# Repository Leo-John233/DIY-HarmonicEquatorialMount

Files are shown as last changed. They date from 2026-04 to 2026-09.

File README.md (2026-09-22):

<div align="center">
  
  
</div>

## 📄 License / 开源协议

本项目采用组合开源协议，对软件和硬件部分分别进行授权：

* **Software / 软件部分** (如固件代码): 采用 [GNU General Public License v3.0 (GPL-3.0)](LICENSE-GPL) 授权，详细信息请参阅 `LICENSE-GPL` 文件
* **Hardware / 硬件部分** (如 PCB 设计、原理图、机械 3D 模型): 采用 [CERN Open Hardware Licence Version 2 - Strongly Reciprocal (CERN-OHL-S v2)](LICENSE-CERN) 授权，详细信息请参阅 `LICENSE-CERN` 文件

若参考了该项目希望能够指明参考来源，注明原作者，保持开源精神，欢迎大家在此基础上进行改进和创新，但请勿将本项目的设计用于商业用途，除非您获得了明确许可

## 🛑致各位试图拿本开源项目“创业”的商业奇才们
本着开源精神，我非常欢迎大家复刻、交流和自己动手做着玩，但如果您是抱着“低价造个赤道仪拿去卖”的伟大商业宏图，并且打算把原作者当免费技术顾问的，请仔细阅读以下几点：

**🚫本项目不提供“保姆级开厂培训”**
开源提供的是设计本身，不是您商业化流水线上的免费技术支持，如果您连最基本的“水平轴承在哪”、“圆弧槽是干啥用的”都看不明白，连 STP 文件导入 SolidWorks 都不知道怎么处理，建议先去补习一下基础的机械常识，我不负责为您解答“怎么装”、“怎么动”、“怎么改”，更不负责给您的工厂流水线工人做技术培训，请不要把原作者当成您的“免费技术顾问”，如果您不懂机械设计，请先学会自己看图纸，学会自己分析问题，学会自己解决问题

**✂️魔改出了 Bug，请自己背锅**
把模型等比缩放、乱改减速机孔位，改完之后跑来跟我抱怨“俯仰调节机构装不上”、“没法适配”、“太难理解”？拜托，自己魔改导致的问题，请不要跑来怪原作者，我都开源了，您还指望我给您的“定制缩水版”做免费 Debug 吗？

**💰嫌贵别用，用了别嫌**
一边刷着小红书觉得这套开源设计“好高级”，一边又跑来跟我吐槽用这套方案“成本涨了200块”、“太麻烦了”，觉得贵、觉得麻烦，您可以不用，既然决定要抄这套作业去赚钱，就别在原作者面前哭穷了，毕竟我也不想看到您辛辛苦苦开了个工厂，结果因为技术问题被客户投诉了还跑来找我背锅

**⚖️友情警告**
想拿这套类似结构随便改个外观就去大规模量产售卖？自己做着玩大家其乐融融，但如果要量产商用，请自己评估好侵权风险，别怪我没提醒过您，出了事请自己承担，别拉上我，开源不等于“免费商用”，如果您想拿去商用，请自己搞定技术壁垒，做好侵权风险评估，做好售后服务准备，做好质量控制准备，做好客户投诉处理准备，做好工厂管理准备，做好资金链管理准备，做好一切商业化运营的准备，不要到时候出了问题还跑来怪原作者

大家都很忙，祝您的“平价赤道仪”大卖，Peace & Love

👉 **[奇文共赏：点击此处阅读“白嫖式创业奇才”的逆天聊天实录](https://github.com/Leo-John233/DIY-Harmonic-Equatorial-Mount/blob/main/images/Chat%20history/readme.md)**

---
## DIY谐波赤道仪（已完成实拍与导星测试）

由于我厌倦了 EQ3D 赤道仪的沉重，我计划用更轻便的谐波赤道仪来替换它。然而市面上的谐波赤道仪价格较高，尤其是与 DIY 可实现的规格相比，因此这个项目就此诞生。该谐波赤道仪旨在不牺牲性能的前提下，兼顾高精度、便携性和经济性

该项目旨在解决业余天文设备中的关键问题：
- 成品支架价格高昂
- 缺乏开放性和灵活性
- 复杂性或与个人设置的不兼容

此款DIY谐波赤道仪优势是：
- 🧰**经济实惠**——总造价2900元左右，CNC加工零件价格低于1800元
- 🪶**相对便携**——不含底座重量7.5公斤
- 🏗️**易于搭建**——专为拥有基本工具的创客设计
- 💪**高性能**——已完成PHD2导星拍摄测试
- ⚠️**关于当前项目状态的说明**⚠️
该项目已完成通电、基础 GoTo、导星和约13kg实际成像负载下的实拍验证，稳定导星时段的 PHD2 总 RMS 通常约为 0.4″ 至 0.6″，不同装配、负载和环境下的结果可能有所差异

## ✨主要特点
| **特征** | **描述** |
| :----- | :----- |
| 安装类型 | GEM德式赤道仪 |
| 传动类型 | 谐波减速器+皮带传动+42步进电机 |
| 有效载重 | 设计最大载重 30 kg（建议配重），无配重设计载重 20-25 kg，当前已完成约 13 kg 实拍验证 |
| 减速器类型 | leaderdrive LHS-25-100-C-III |
| 控制系统 | OnStep/OnStepx |
| 连接类型 | USB-B；WIFI；蓝牙；集成DS3231SN时钟芯片 |
| 硬件功能 | RA轴制动器；RA/DEC轴光电传感器限位；DEC/RA轴光电传感器原点；<br>同时兼容step/dir，spi两种驱动模式(即兼容tmc2209，tmc5160)；12/24v输入 |
| 预计成本 | 2900 RMB |
| 预计重量 | 9.5 kg（包含鸠尾槽和纬度座） |
| 已测导星表现 | 稳定时段 PHD2 总 RMS 通常约为 0.4″ 至 0.6″ |

---

## 最终成效

自制谐波赤道仪的核心部件为 Leaderdrive 拆机二手工业谐波减速器，也适用于同规格的 25-100 谐波减速器






---

## 实拍与导星测试

本次拍摄目标为 **Herschel 36**

Herschel 36

| **实拍项目** | **配置** |
| :----- | :----- |
| 主摄影器材 | 铁皮桶全改小黑，搭配 MPCC 彗差校正镜 |
| 主相机 | Nikon D7000 |
| 导星相机 | ZWO ASI662MC |
| 实际成像负载 | 约 13 kg |
| 测试环境 | 微风 |

## 当前验证状态

- [√] 主控板通电和基础通信
- [√] OnStep ASCOM 连接
- [√] 基础 GoTo 和恒星时跟踪
- [√] PHD2 校准和闭环导星
- [√] Dither 和 Settling
- [√] 约 52 分 45 秒连续导星记录
- [√] 约 13 kg 实际成像负载下的 Herschel 36 实拍
- [√] 不同载重和重心位置下的多夜重复测试
- [√] 无配重与带配重状态下的系统对比
- [ ] 关闭导星修正和 Dither 后的长时间本征周期误差测试
- [ ] 不同焦距、曝光时间和环境条件下的长期实拍验证

## PHD2 导星测试

### 测试配置

| 项目 | 配置 |
| :--- | :--- |
| 测试软件 | PHD2 Guiding 2.6.13 |
| 赤道仪连接 | OnStep ASCOM |
| 导星相机 | ZWO ASI662MC |
| 导星焦距 | 200 mm |
| 导星相机像元尺寸 | 2.9 μm |
| 导星图像比例 | 约 2.99″/px |
| 导星曝光 | 0.2 s |
| 实际成像负载 | 约 13 kg |
| 测试环境 | 微风 |
| 完整记录时长 | 52 分 45 秒 |

### 结果汇总

| 测试片段 | RA RMS | Dec RMS | 总 RMS | 说明 |
| :--- | ---: | ---: | ---: | :--- |
| 稳定导星片段 | 0.43″ | 0.50″ | 0.66″ | PHD2 实时统计截图 |
| 52 分 45 秒完整记录 | 0.45″ | 0.82″ | 0.94″ | 包含 Dither、Settling 和少量异常峰值 |

实际使用过程中，稳定导星阶段的总 RMS 通常约为 0.4″ 至 0.6″。稳定片段截图显示总 RMS 为 0.66″，完整记录由于包含 Dither、Settling 和少量异常峰值，总 RMS 为 0.94″

### 结果分析

- **稳定阶段两轴误差较为均衡**：RA RMS 为 0.43″，Dec RMS 为 0.50″，两轴差值较小，未表现出明显的单轴持续振荡。总 RMS 为 0.66″，按 2.99″/px 的导星图像比例换算约为 0.22 px，其中 RA 约为 0.14 px，Dec 约为 0.17 px
- **完整记录的 RMS 主要由 Dec 瞬态波动拉高**：完整记录中的 RA RMS 为 0.45″，与稳定片段接近，说明 RA 长时间表现基本保持一致。Dec RMS 上升至 0.82″，表明完整记录中的 Dither、Settling、微风或少量异常峰值主要影响了 Dec 统计结果，不代表稳定跟踪阶段持续存在 0.82″ 的 Dec 误差
- **约 13 kg 实际负载下维持稳定导星**：在铁皮桶全改小黑、Nikon D7000、MPCC 和导星系统组成的约 13 kg 成像负载下，稳定阶段未观察到明显发散或持续性机械振荡，说明当前结构刚性、传动控制和导星响应能够满足实际成像需求
- **0.2 s 导星曝光体现了较快的修正响应**：较短曝光有助于快速修正误差，但也更容易受到视宁度和瞬时扰动影响。因此，0.4″ 至 0.6″ 应视为本次设备、参数和环境组合下的实测表现，不应直接作为所有场景下的固定性能指标
- **频域结果不能直接作为本征周期误差**：频域分析中选中的低频分量周期约为 2206.6 s，显示振幅约为 0.1″。由于数据来自导星记录，并包含低频漂移、Dither 和 Settling，该结果只能用于观察频率成分，不能直接认定为谐波减速器的本征周期误差

<details>
<summary>展开查看 PHD2 测试截图与频域分析</summary>

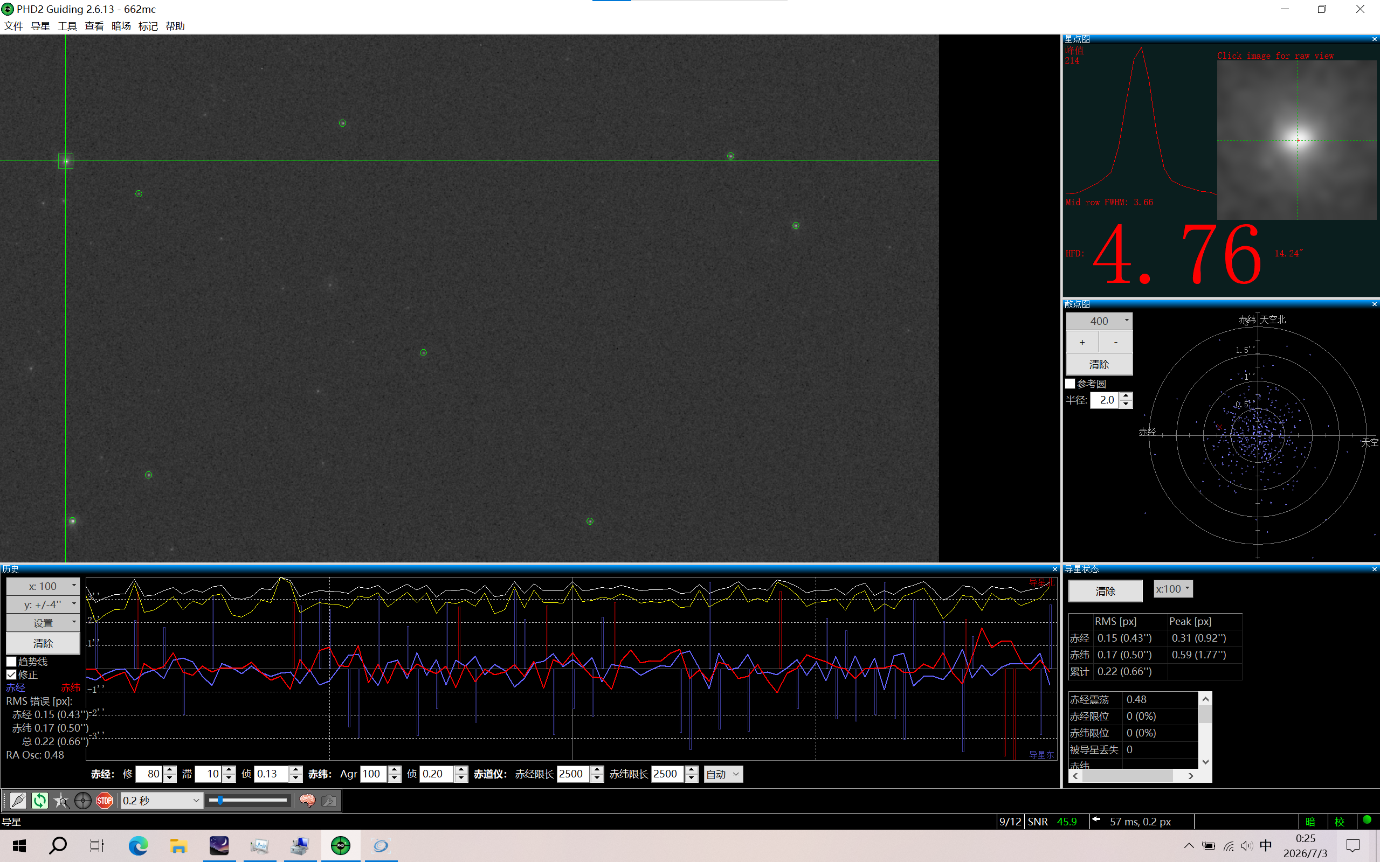
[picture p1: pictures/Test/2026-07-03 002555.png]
PHD2 stable guiding


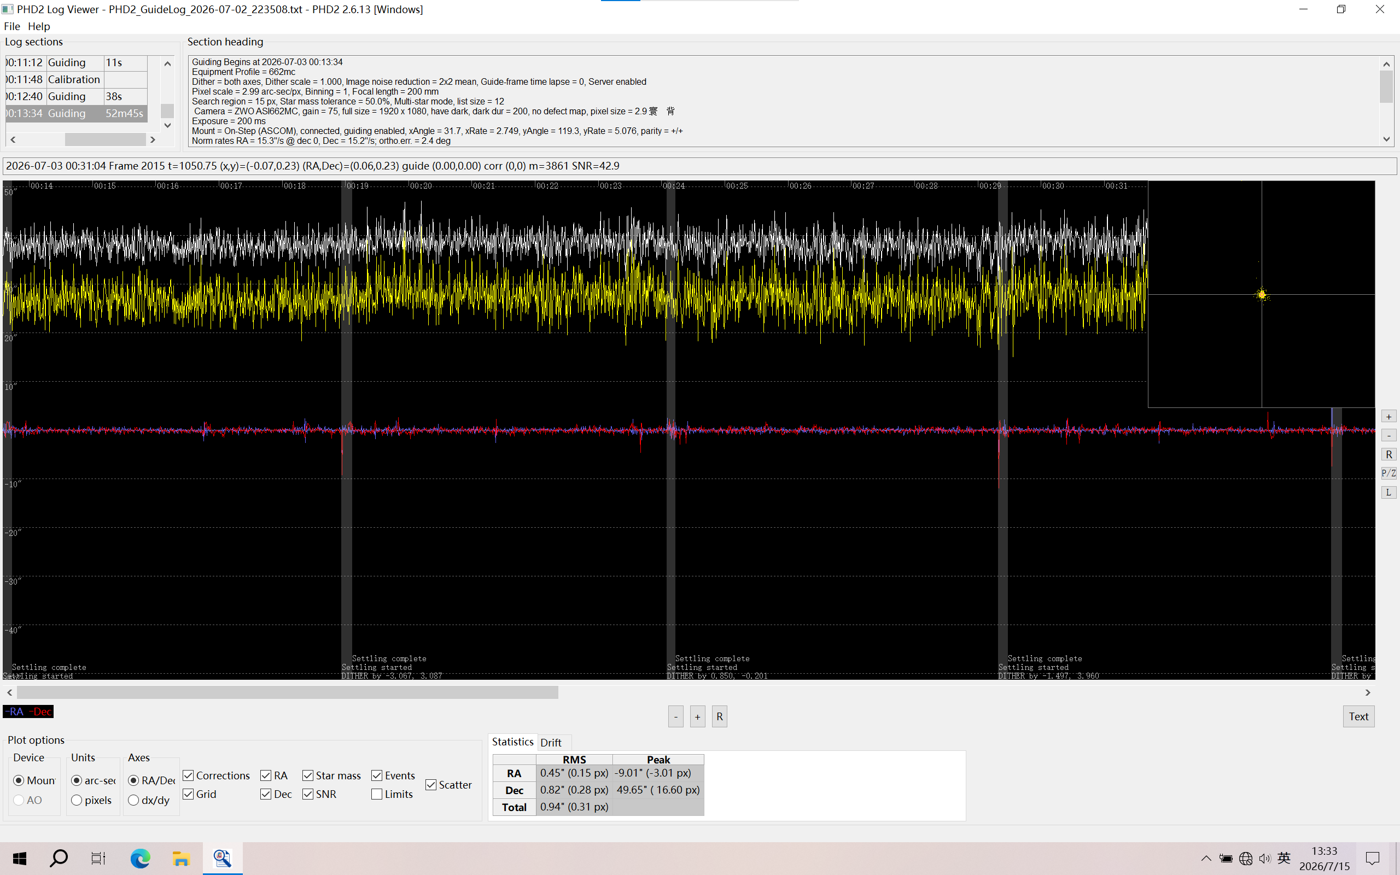
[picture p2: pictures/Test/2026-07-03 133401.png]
PHD2 complete log


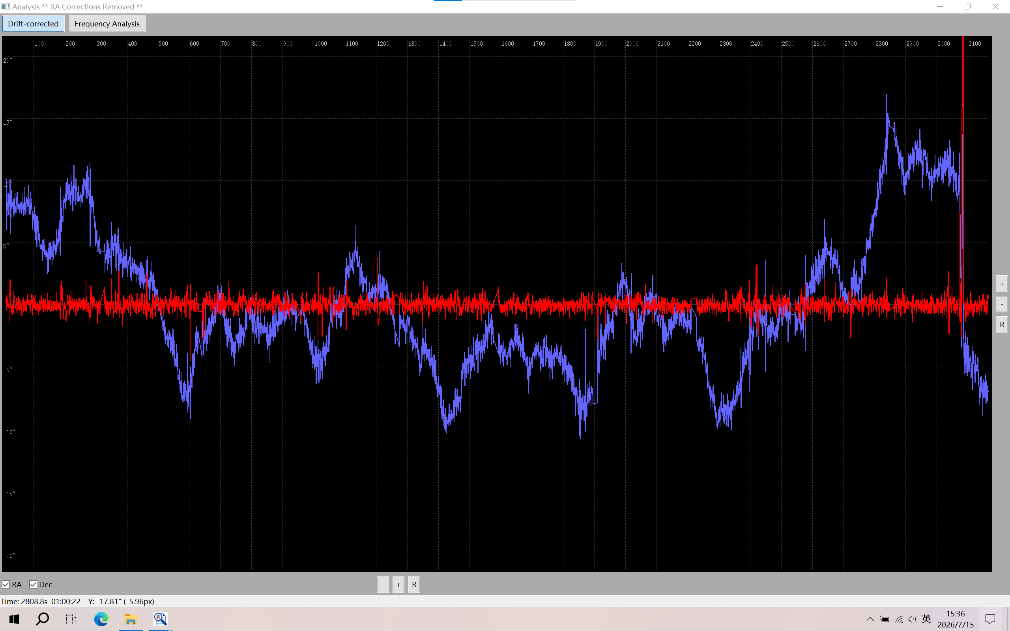
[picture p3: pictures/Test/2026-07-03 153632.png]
PHD2 drift-corrected analysis


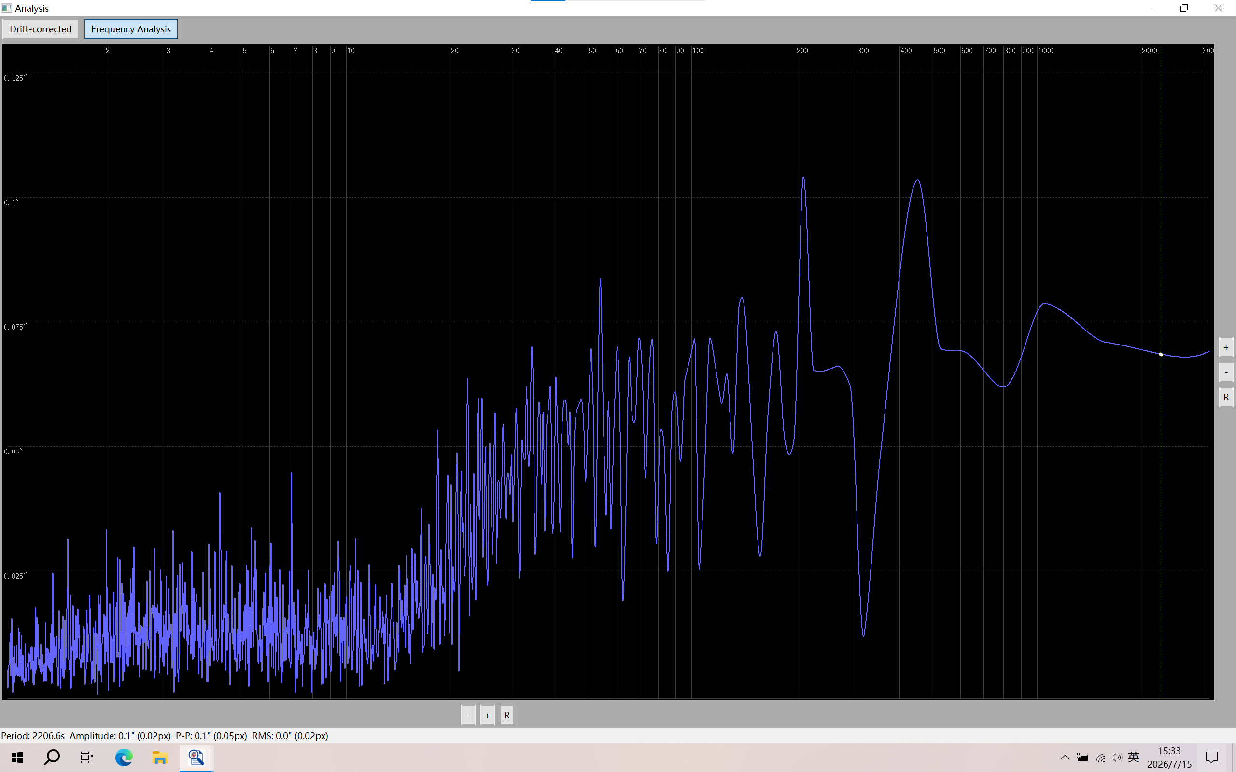
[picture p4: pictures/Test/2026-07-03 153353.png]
PHD2 frequency analysis


移除 RA 导星修正后的曲线仍包含低频漂移、Dither 和 Settling 的影响，不能直接将整段曲线的峰峰值视为谐波减速器的本征周期误差

频域分析中选中的低频分量周期约为 2206.6 s，软件显示振幅约为 0.1″。该结果仅用于观察频率成分，不能替代关闭导星修正和 Dither 后进行的长时间无导星周期误差测试

</details>

---

## 🔗 物料清单 (BOM)

请参阅 [BOM.md](https://github.com/Leo-John233/DIY-Harmonic-Equatorial-Mount/tree/main/BOM)

**预计总成本：约2500RMB（含纬度座）**

本项目的主体结构高度依赖定制，主要部件包含两台 25-100 规格的谐波减速器，提供了极高的传动比与扭矩，底座接口可根据个人习惯适配主流的三脚架

*注：价格为近似值，可能因电机供应商、CNC 加工批次和地点而异*

---

## 🔌电子部分概览

控制系统完全采用定制设计，并围绕紧凑结构构建，它包括：

* **基于 ESP32-WROOM-32E16N 的主控核心**，运行强大的 [OnStep/OnStepX](https://onstep.groups.io/g/main/wiki) 系统
* **搭配 ESP07S 无线连接**，提供高效的无线/有线通讯
* **TMC系列步进电机驱动器**，实现赤经与赤纬轴精确、静音的微步进控制与指向
* **高效电源管理方案**，板载 TPS5450 降压模块和 AMS1117 LDO 稳压芯片，确保高负载下系统电压的纯净与稳定
* 集成 **零位传感器和限位开关** 接口，在运行中保障设备的安全
* 支持通过 Wi-Fi、蓝牙或 USB 路由进行远程控制，无缝对接主流天文摄影软件生态 (N.I.N.A., INDI, ASCOM 等)
* 控制板在 PCB 走线设计上充分考虑了扩展性需求，通过主板驱动器插槽旁的排针跳线 (Jumpers)，您可以轻松地在先进的 **SPI 智能控制模式**和传统的 **STEP/DIR 独立模式**之间进行物理切换(切换后需刷写固件)

* **TMC5160 SPI 模式 (推荐配置) 🚀**
    * **硬件设置**：使用跳线帽闭合 SPI 专用的针脚组，将 ESP32 的 SPI 总线直接连接至 TMC5160 驱动器
    * **系统优势**：彻底告别手动调节电位器，允许 OnStep 固件直接读取和写入寄存器，您可以在 Web 界面或 `Config.h` 中实时配置运行/保持电流、精确设置细分数（Microstepping），并在 StealthChop（极致静音）和 SpreadCycle（高动态扭矩）模式之间智能切换，最大化释放谐波减速器的性能
    * **固件配合**：在 `Config.h` 中将赤经/赤纬驱动模型定义为 `TMC5160_SPI`

* **传统 STEP/DIR 模式 (向下兼容) 🔌**
    * **硬件设置**：断开 SPI 通讯跳线
    * **适用场景**：作为一种可靠的底层回退方案。如果您需要临时替换为普通的 A4988、DRV8825，或者仅使用 TMC 驱动器的 Standalone (独立运行) 模式，此设计提供了极大的硬件容错率和维修便利性
    * **固件配合**：需要在 `Config.h` 中精确填写您通过跳线帽设定的细分值，并**必须手动使用万用表和陶瓷螺丝刀**调节驱动器上的 VREF 电位器来设定电机电流

所有电路板原理图及 PCB Layout（严格把控了安全间距、过孔尺寸和大电流线宽）均使用开源工具设计，您可以在 [JLC PCB](https://member.jlc.com/?spm=PCB.Homepage) 订购 PCB或对其进行重新组合以满足您的需求

### PCB 制作与装配说明

PCB front

PCB reverse-side TMC5160 installation

PCB reverse-side TMC2209 installation

PCB 制作和装配建议按以下顺序进行：

1. **提交 PCB 文件**
   * 将仓库中对应版本的 Gerber 压缩包直接上传至 PCB 厂商
   * 下单前检查板框尺寸、安装孔、槽位和连接器开口，避免生产平台自动缩放或修改外形
   * 如果自行修改板厚、铜厚、表面处理或元件封装，需要重新确认外壳间隙、连接器高度和大电流走线能力

2. **核对元件和方向**
   * 焊接前根据原理图、BOM、PCB 丝印和封装方向逐项核对元件
   * 重点检查二极管、LED、电解电容、稳压芯片、ESP32、ESP-07S 和其他有方向要求的器件
   * CR1220 电池按 PCB 丝印方向安装，照片所示安装方式为正极朝外
   * ESP32 天线区域附近不要布置金属挡板、屏蔽片或紧贴外壳，以免影响无线连接

3. **建议焊接顺序**
   * 先焊接电阻、电容、二极管和小型 IC 等低矮贴片器件
   * 再焊接电源模块、排针、驱动器插座、按键和 LED 接口
   * 最后安装 XH2.54 插座、USB、网络接口、DC 插座、XT60 和其他较高连接器
   * TMC 驱动器、ESP 模块和纽扣电池应在完成短路检查和基础供电测试后再安装

4. **驱动器安装**
   * 驱动器安装在 PCB 背面，插入前必须核对 PCB 丝印与驱动器上的 `GND`、`VM`、`EN`、`STEP` 和 `DIR` 引脚
   * 不同厂商的 TMC2209 或 TMC5160 模块可能存在引脚、焊盘或散热结构差异，不能只根据模块外观判断方向
   * 使用 TMC5160 SPI 模式时闭合对应 SPI 跳线，并在固件中选择 `TMC5160_SPI`
   * 使用 TMC2209 或其他 STEP/DIR 驱动器时断开 SPI 跳线，并按照实际硬件设置填写细分参数和驱动电流
   * 驱动器插反或带电插拔可能立即损坏驱动器和主控板

5. **首次通电检查**
   * 通电前使用万用表检查主电源正负极之间是否存在明显短路
   * 首次测试建议使用带限流功能的实验电源，并从较低限流值开始
   * 首次通电时不要连接电机、传感器和驱动器，先确认电源部分没有异常发热，并检查主要电压轨是否正常
   * 确认主控、USB 通信和无线连接正常后，再逐个安装驱动器并连接 RA、Dec 电机
   * 初次电机测试应使用较低电流和较低速度，确认转向、原点和限位逻辑正确后再提高参数

6. **接口连接**
   * `LIMIT-RA`、`LIMIT-DEC`、`HOME-RA` 和 `HOME-DEC` 分别连接对应轴的限位和原点传感器
   * `RA-XH2.54`、`DEC-XH2.54` 和 `BRAKE` 接口应根据原理图确认引脚顺序后连接
   * 状态灯、连接灯和电源灯接口需要注意 LED 极性
   * 不建议同时连接多个主电源入口，除非已根据原理图确认其连接关系和使用方式

> 💡**警告：任何焊接、驱动器插拔、跳线调整、传感器接线或电机接线操作都必须在主电源和 USB 供电完全断开后进行，首次上电前应再次检查电源极性、焊锡短路、驱动器方向和连接器引脚顺序**

## 💻固件配置与刷写

谐波赤道仪的主控搭载了 **ESP32-WROOM-32E (16MB)**，这款大容量核心不仅能轻松运行复杂的 [OnStep / OnStepX](https://onstep.groups.io/g/main/wiki) 固件，还为内置星表、高精度对位模型 (Pointing Model) 以及功能丰富的 Smart Web UI 留出了充足的存储空间

请参阅 [Firmware_Setup.md](https://github.com/Leo-John233/DIY-Harmonic-Equatorial-Mount/blob/main/software/Firmware_Setup.md) 获取完整的 `Config.h` 参数表及详细引脚映射

---

## 🛠️机械部分组装指南

请参阅 [Assembly.md](https://github.com/Leo-John233/DIY-Harmonic-Equatorial-Mount/blob/main/hardware/Assembly.md)

每个组件都经过精心挑选或设计，以确保高机械精度和易于组装，从 CNC 加工的坚固铝制主体、25-100 谐波减速器，到步进电机和控制器的 3D 打印防护外壳，每一步都经过了严格的测试与指向模型校准，以实现亚角秒级的跟踪精度

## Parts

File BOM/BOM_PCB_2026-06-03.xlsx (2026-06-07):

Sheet: bom模板
 |  |  |  | Bill of Materials | BOM_Leo_V1_STEP/DIR/SPI(已验证)_PCB1_2026-06-03
 |  |  |  | Project Title： | OnStep
 |  |  |  | Variant:
 |  |  |  | Report Time： | 2026年6月3日 21:4:49
No. | Quantity | Comment | Designator | Footprint | Value | Manufacturer Part | Manufacturer | Supplier Part | Supplier | LCSC Price | Total
1 | 1 | CR1220-2 | B1 | BAT-SMD_CR1220-2 |  | CR1220-2 | QIJEY | C70381 | LCSC |  | #VALUE!
2 | 2 | TS-1101-C-W | BOOT, RESET | SW-SMD_L6.0-W3.3-LS8.0 |  | TS-1101-C-W | XKB Connectivity(中国星坤) | C318938 | LCSC |  | #VALUE!
3 | 1 | WAFER-XH254Z-2A | BRAKE | CONN-TH_2P-P2.50_XH-2A_3045048 |  | WAFER-XH254Z-2A | HANBO(汉博) | C7432682 | LCSC |  | #VALUE!
4 | 3 | 100uF | C1, C6, C7 | C1210 | 100uF | EMK325ABJ107MM-T | TAIYO YUDEN(太诱) | C394395 | LCSC |  | #VALUE!
5 | 2 | 4.7uF | C2, C3 | C0603_1 | 4.7uF |  |  |  |  |  | #VALUE!
6 | 4 | 10nF | C4, C5, C8, C10 | C0603_1 | 10nF |  |  |  |  |  | #VALUE!
7 | 1 | 10uF | C9 | C0603_1 | 10uF |  |  |  |  |  | #VALUE!
8 | 4 | 10uF | C11, C13, C15, C17 | C0805 | 10uF | CL21A106KAYNNNE | SAMSUNG(三星) | C15850 | LCSC |  | #VALUE!
9 | 4 | 100nF | C12, C14, C16, C18 | C0603 | 100nF | CL10B104KB8NNNC | SAMSUNG(三星) | C1591 | LCSC |  | #VALUE!
10 | 5 | 100nF | C19, C24, C25, C26, C27 | C0603 | 100nF |  |  |  |  |  | #VALUE!
11 | 1 | 10uF | C20 | CASE-A_3216 |  | T491A106K010AT | KEMET(基美) | C1508940 | LCSC |  | #VALUE!
12 | 1 | 100nF | C21 | C0603 | 100nF | CGA0603X7R104K500JT | HRE(芯声) | C6119867 | LCSC |  | #VALUE!
13 | 1 | 10uF | C22 | C0603 | 10uF | CGA0603X5R106K100JT | HRE(芯声) | C6119842 | LCSC |  | #VALUE!
14 | 1 | 1uF | C23 | C0603 | 1uF |  |  |  |  |  | #VALUE!
15 | 2 | 100uF | C28, C29 | CAP-SMD_BD6.3-L6.6-W6.6-LS7.3-FD-H7.7 | 100uF | JVJ50V100M6x8 | JIERR(捷而瑞) | C46550415 | LCSC |  | #VALUE!
16 | 1 | XT30U-M | CN1 | CONN-TH_XT30U-M |  | XT30U-M | AMASS(艾迈斯) | C99101 | LCSC |  | #VALUE!
17 | 1 | RA-XH254 | CN2 | CONN-TH_XH-4A |  | WAFER-XH254Z-4A | HANBO(汉博) | C7432684 | LCSC |  | #VALUE!
18 | 1 | DEC-XH254 | CN3 | CONN-TH_XH-4A |  | WAFER-XH254Z-4A | HANBO(汉博) | C7432684 | LCSC |  | #VALUE!
19 | 1 | SK1045C | D1 | SMC_L6.9-W5.9-LS7.9-RD |  | SK1045C | R+O(宏嘉诚) | C18199212 | LCSC |  | #VALUE!
20 | 1 | SMAJ28A | D2 | SMA_L4.3-W2.6-LS5.2-RD |  | SMAJ28A | 晶导微电子 | C353458 | LCSC |  | #VALUE!
21 | 3 | 1N5819W | D3, D6, D7 | SOD-123_L2.7-W1.6-LS3.7-RD |  | 1N5819W | GOODWORK(固得沃克) | C41431973 | LCSC |  | #VALUE!
22 | 1 | SMF5.0A | D4 | SOD-123FL_L2.7-W1.8-LS3.8-RD |  | SMF5.0A | R+O(宏嘉诚) | C19077497 | LCSC |  | #VALUE!
23 | 1 | 1N4007 | D5 | SMA_L4.3-W2.5-LS5.0-RD |  | 1N4007 | TWGMC(迪嘉) | C727081 | LCSC |  | #VALUE!
24 | 1 | PRTR5V0U2X | D9 | SOT-143-4_L2.9-W1.3-P1.92-LS2.4-BL |  | PRTR5V0U2X | TECH PUBLIC(台舟) | C2827688 | LCSC |  | #VALUE!
25 | 1 | DC005 | DC1 | DC-IN-TH_DC005 |  | DC005 | SHOU HAN(首韩) | C431533 | LCSC |  | #VALUE!
26 | 1 | K0805L100AR | F1 | F0805 |  | K0805L100AR | KUU | C2892413 | LCSC |  | #VALUE!
27 | 3 | HC-ZH1.5-2A | HOME-BUTTON, POWER-LED, STATUS-LED | CONN-TH_2P-P1.50_HCTL_HC-ZH1.5-2A |  | HC-ZH1.5-2A | HCTL(华灿天禄) | C2845550 | LCSC |  | #VALUE!
28 | 1 | 15uH | L1 | IND-SMD_L7.0-W6.6 | 15uH | FXL0650-150-M | cjiang(长江微电) | C475522 | LCSC |  | #VALUE!
29 | 1 | GL0603UR01 | LINK-LED | LED0603-FD |  | GL0603UR01 | Guiguang light(桂光光电) | C51933292 | LCSC |  | #VALUE!
30 | 2 | SS8050 | Q1, Q2 | SOT-23-3_L2.9-W1.3-P1.90-LS2.4-BR |  | SS8050 | JSMSEMI(杰盛微) | C916392 | LCSC |  | #VALUE!
31 | 1 | 10K | R1 | R0603_1 | 10K |  |  |  |  |  | #VALUE!
32 | 1 | 3.16K | R2 | R0603_1 | 3.16K |  |  |  |  |  | #VALUE!
33 | 2 | 510Ω | R3, R4 | R0603 | 510Ω | 0603WAF5100T5E | UNI-ROYAL(厚声) | C23193 | LCSC |  | #VALUE!
34 | 2 | 12kΩ | R5, R6 | R0603 | 12kΩ | 0603WAF1202T5E | UNI-ROYAL(厚声) | C22790 | LCSC |  | #VALUE!
35 | 1 | 2K | R7 | R0603 | 2K |  |  |  |  |  | #VALUE!
36 | 5 | 4.7K | R8, R12, R13, R14, R15 | R0603 | 4.7K |  |  |  |  |  | #VALUE!
37 | 2 | 10K | R9, R11 | R0603 | 10K |  |  |  |  |  | #VALUE!
38 | 2 | 3.3K | R10, R16 | R0603 | 3.3K |  |  |  |  |  | #VALUE!
39 | 1 | 5301-6P6C | RJ1 | RJ45-TH_5301-6P6C |  | 5301-6P6C | EVERCOM(恒连) | C3097716 | LCSC |  | #VALUE!
40 | 2 | 4.7kΩ | RN1, RN2 | RES-ARRAY-SMD_0603-8P-L3.2-W1.6-BL | 4.7kΩ | 4D03WGJ0472T5E | UNI-ROYAL(厚声) | C1980 | LCSC |  | #VALUE!
41 | 2 | ZX-PZ1.27-1-2PZZ | RST, SPI | HDR-TH_2P-P1.27-V-M-2 |  | ZX-PZ1.27-1-2PZZ | Megastar(兆星) | C41370734 | LCSC |  | #VALUE!
42 | 4 | M3螺孔 | TP1, TP2, TP3, TP4 | M3螺孔外直径6MM |  |  |  |  |  |  | #VALUE!
43 | 1 | TPS5450DDAR | U1 | SOP-8_L4.9-W3.9-P1.27-LS6.0-BL-EP |  | TPS5450DDAR | TI(德州仪器) | C114425 | LCSC |  | #VALUE!
44 | 2 | AMS1117-3.3 | U2, U3 | SOT-223-4_L6.5-W3.5-P2.30-LS7.0-BR |  | AMS1117-3.3 | UMW(友台半导体) | C347222 | LCSC |  | #VALUE!
45 | 1 | CP2102-GMR | U4 | WQFN-28_L5.0-W5.0-P0.50-BL-EP3.2 |  | CP2102-GMR | SKYWORKS/SILICON LABS(芯科) | C6568 | LCSC |  | #VALUE!
46 | 1 | ESP32-WROOM-32E-N16 | U5 | WIFI-SMD_ESP32-WROOM-32E |  | ESP32-WROOM-32E-N16 | ESPRESSIF(乐鑫) | C701343 | LCSC |  | #VALUE!
47 | 1 | ESP-07S | U6 | WIRELM-SMD_ESP-07S | 2.4GHz | ESP-07S | Ai-Thinker(安信可) | C82895 | LCSC |  | #VALUE!
48 | 1 | DS3231SN# | U7 | SOIC-16_L10.3-W7.5-P1.27-LS10.3-BL |  | DS3231SN# | ADI(亚德诺)/MAXIM(美信) | C722469 | LCSC |  | #VALUE!
49 | 1 | HOME-RA | U8 | CONN-TH_XH-3A |  | HOME-RA | HANBO(汉博) | C7432683 | LCSC |  | #VALUE!
50 | 1 | LIMIT-RA | U9 | CONN-TH_XH-3A |  | LIMIT-RA | HANBO(汉博) | C7432683 | LCSC |  | #VALUE!
51 | 1 | HOME-DEC | U10 | CONN-TH_XH-3A |  | HOME-DEC | HANBO(汉博) | C7432683 | LCSC |  | #VALUE!
52 | 1 | LIMIT-DEC | U11 | CONN-TH_XH-3A |  | LIMIT-DEC | HANBO(汉博) | C7432683 | LCSC |  | #VALUE!
53 | 1 | TMC2209-RA | U12 | TMC2209 |  |  |  |  |  |  | #VALUE!
54 | 1 | TMC2209-DEC | U13 | TMC2209 |  |  |  |  |  |  | #VALUE!
55 | 1 | USB-B10-BRW | USB1 | USB-B-TH_USB-B10-BRW |  | USB-B10-BRW | XUNPU(讯普) | C720549 | LCSC |  | #VALUE!
56 | #VALUE!

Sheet: Field汇总
Project Title | OnStep
Borard Title | Leo_V1_STEP/DIR/SPI(已验证)
Schematic Title | Schematic1
PCB Title | PCB1
Variant Name
Total Quantity | 92
Report Time | 21:4:49
Report Date | 2026年6月3日
Report Date&Time | 2026年6月3日 21:4:49
File Name | BOM_Leo_V1_STEP/DIR/SPI(已验证)_PCB1_2026-06-03
Filter Option | Add into BOM:no;

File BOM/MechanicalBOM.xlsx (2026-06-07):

纬度座部分
名称 | 规格 | 数量
塞打螺栓 | M8*10*M6 | 2 | https://detail.tmall.com/item.htm?id=601075915248&skuId=5681343815429
塞打螺栓 | M8*8*M6 | 2 | https://detail.tmall.com/item.htm?id=601075915248&skuId=5790216147369
一字塞打螺栓 | M8*10*M6 | 2 | https://detail.tmall.com/item.htm?id=706829568952&skuId=5886571346823
12.9级杯头螺丝 | M5*18 | 8 | https://detail.tmall.com/item.htm?id=636950471592&skuId=4572720393404
304不锈钢家具大平头倒边内六角螺丝 | M6*12 | 1 | https://detail.tmall.com/item.htm?id=859903073791
304不锈钢内螺纹圆柱销 | Φ12*25*M6 | 1 | https://detail.tmall.com/item.htm?id=597217503705&skuId=5510229308653
小微型推力球平面轴承 | F8-14M 尺寸8*14*4 | 2 | https://detail.tmall.com/item.htm?id=586706057051&skuId=5729732388208
304不锈钢一字开槽轴位螺丝钉 | φ6*6(M5*6) | 2 | https://item.taobao.com/item.htm?id=632002464537&skuId=5559277728820
圆切边法兰铜合金无油衬套黄铜铜套 | 8-15(27*4/8*12*15)-圆光 | 2 | https://detail.tmall.com/item.htm?id=561388884402
12.9级杯头螺丝 | M5*14 | 2 | https://detail.tmall.com/item.htm?id=587639753812&skuId=4942038499904
薄头内六角螺丝钉DIN7984 | M3*4 | 4 | https://detail.tmall.com/item.htm?id=611120761311&skuId=4924269517558
铜垫片 | M8*12*0.5 | 4 | https://detail.tmall.com/item.htm?id=626549373648
铜垫片 | M5*9*0.5 | 2 | https://detail.tmall.com/item.htm?id=626549373648
不锈钢超薄垫片 | M8*12*0.1 | 4 | https://detail.tmall.com/item.htm?id=610746766031
不锈钢超薄垫片 | M8*12*0.2 | 4 | https://detail.tmall.com/item.htm?id=610746766031
12.9级薄头内六角螺丝DIN7984 | M4*16 | 8 | https://detail.tmall.com/item.htm?id=600935021724
12.9级薄头内六角螺丝DIN7984 | M4*12 | 4 | https://detail.tmall.com/item.htm?id=600935021724
12.9级高强度镀镍薄头内六角螺丝 | M6*12 | 4 | https://detail.tmall.com/item.htm?id=852888071845
带钩拉簧 | 0.8*5*20 | 4 | https://detail.tmall.com/item.htm?id=625341852315
304不锈钢圆柱销销钉 | M3*18 | 4 | https://detail.tmall.com/item.htm?id=587625731480
304不锈钢薄头内六角螺丝 | M6*14 | 2 | https://detail.tmall.com/item.htm?id=15880165683
304不锈钢薄头内六角螺丝钉DIN7984 | M3*10 | 4 | https://detail.tmall.com/item.htm?id=611120761311
RN方形四方防松锁紧螺母螺 | RN-M8*1.0 | 2 | https://item.taobao.com/item.htm?ali_trackid=282_ddc27389fe7606c30299c8967ceb7956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
304不锈钢牙条细牙丝杆 | M8*120 | 1 | https://detail.tmall.com/item.htm?id=862294829769&skuId=5680688716227
梅花手拧螺栓 | M6x45mm | 2 | https://item.taobao.com/item.htm?id=973695181639
赤道仪部分
名称 | 规格 | 数量
铝合金四方六面螺母 | 15*15*15-M5 | 8 | https://item.taobao.com/item.htm?id=734244001867
铝合金四方六面螺母 | 10*10*10-M4 | 2 | https://item.taobao.com/item.htm?id=734244001867&skuId=5096386476347
304不锈钢家具大平头倒边内六角螺丝 | M4*8 | 4 | https://item.taobao.com/item.htm?id=743652912113
304不锈钢家具大平头倒边内六角螺丝 | M6*8 | 16 | https://item.taobao.com/item.htm?id=743652912113
304不锈钢圆头内六角螺丝 | M3*10 | 16 | https://detail.tmall.com/item.htm?id=587776166655
304不锈钢螺母 | M3 | 10 | https://detail.tmall.com/item.htm?id=1013711773809
内六角螺丝12.9级高强度镀镍杯头螺栓 | M4*45半牙 | 4 | https://detail.tmall.com/item.htm?id=621643553473
内六角螺丝12.9级高强度镀镍杯头螺栓 | M4*40半牙 | 24 | https://detail.tmall.com/item.htm?id=621643553473
304/316不锈钢尼龙锁紧螺母 | M4 | 24 | https://detail.tmall.com/item.htm?id=556902193652
六角铜柱单头铜螺柱 | M3*25+4 | 6 | https://detail.tmall.com/item.htm?id=601878143598
六角铜柱单头铜螺柱 | M3*15+3 | 4 | https://detail.tmall.com/item.htm?id=601878143598
12.9级半牙内六角螺丝 | M3*45 | 4 | https://detail.tmall.com/item.htm?id=695021175011
内六角螺丝12.9级高强度镀镍杯头螺栓 | M4*20 | 25 | https://detail.tmall.com/item.htm?id=621643553473
12.9级薄头内六角螺丝DIN7984 | M4*16 | 6 | https://detail.tmall.com/item.htm?id=600935021724
步进电机电磁制动器弹簧挤压机械刹车12v | 圆轴5×4.5mm | 1 | https://item.taobao.com/item.htm?id=833619009457
雷赛电机42CM06 | 双轴电机42CM06-SZ/47高度 | 1 | https://item.taobao.com/item.htm?id=670665930208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
雷赛电机42CM06 | 单轴电机42CM06-SZ/47高度 | 1 | https://item.taobao.com/item.htm?id=670665930208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
槽型形光电开关 | NPN | 4 | https://detail.tmall.com/item.htm?id=742487483554
土八热熔螺母 | M3*6*4.6 | 10 | https://detail.tmall.com/item.htm?id=809364062256

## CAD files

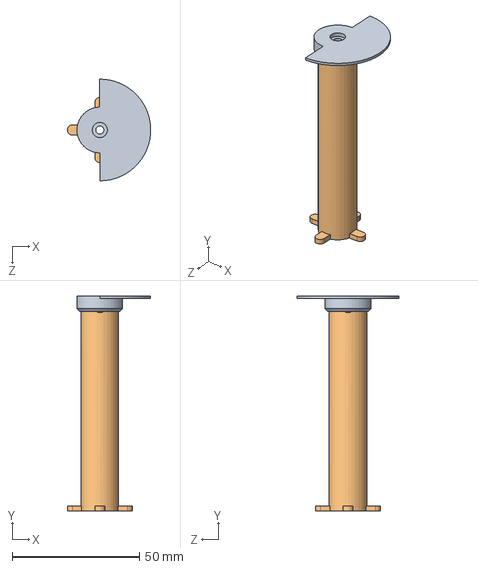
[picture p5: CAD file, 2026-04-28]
hardware/SW2024/赤道仪本体/组合体/RA轴+180度.SLDASM
32.8 x 84.5 x 40.0 mm
RA轴
180度限位盘

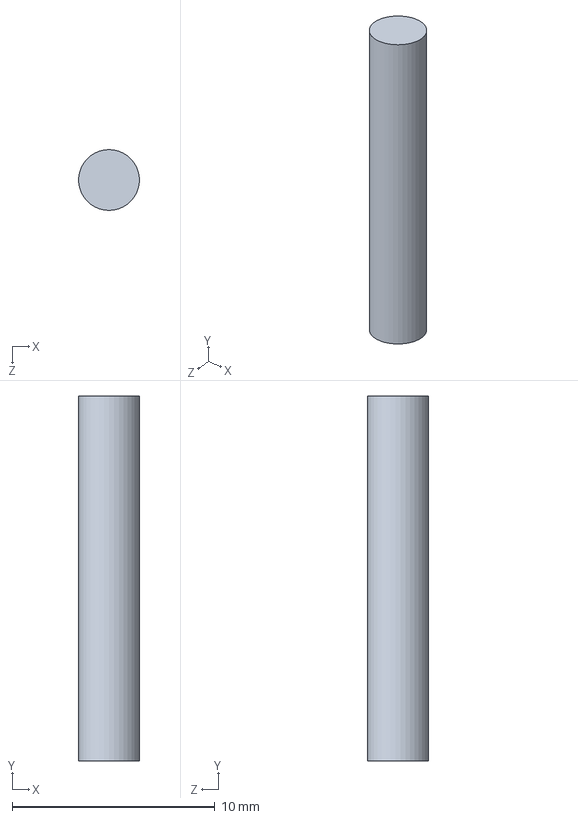
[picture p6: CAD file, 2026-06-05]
hardware/SW2024/纬度座/Spring Pin 3x10.SLDPRT
2.99 x 18.0 x 3.00 mm

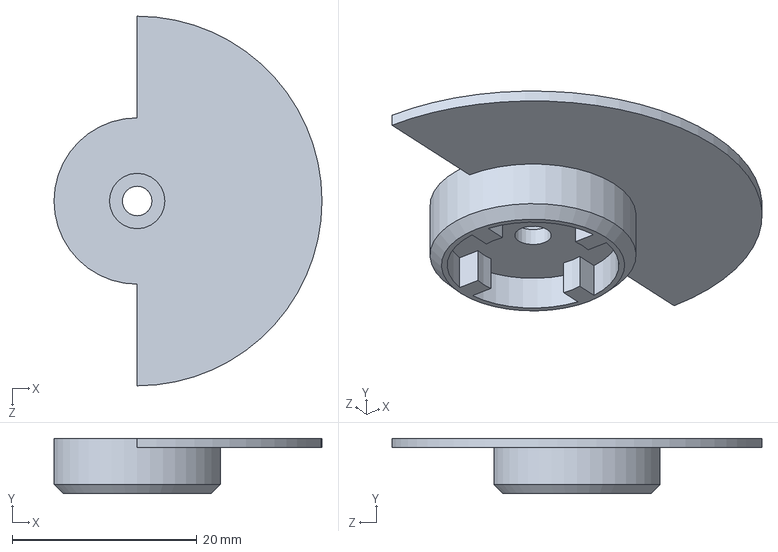
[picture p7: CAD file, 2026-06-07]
hardware/SW2024/赤道仪本体/180度限位盘.SLDPRT
29.0 x 6.00 x 40.0 mm

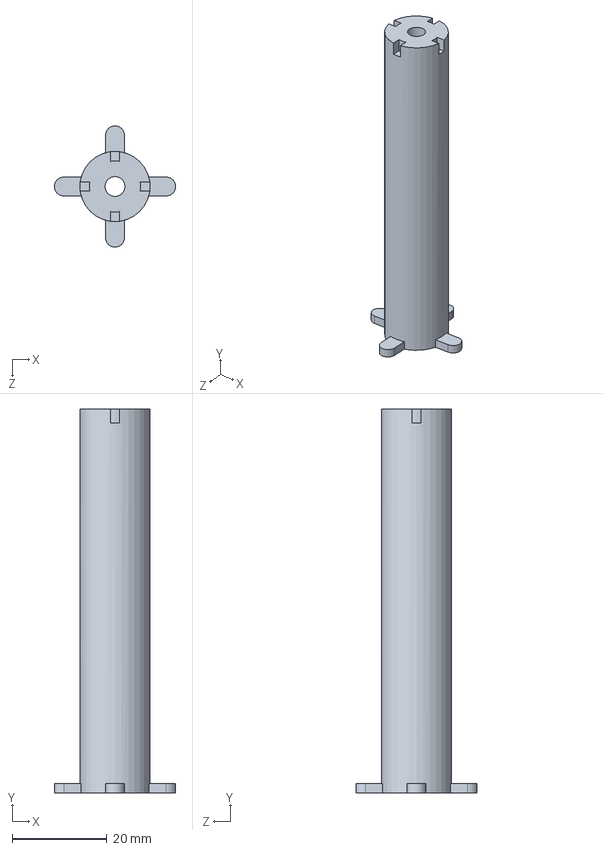
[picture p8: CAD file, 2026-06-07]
hardware/SW2024/赤道仪本体/RA轴.SLDPRT
25.6 x 81.0 x 25.6 mm

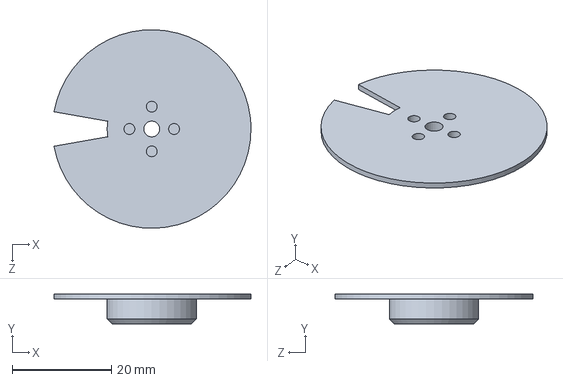
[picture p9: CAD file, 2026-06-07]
hardware/SW2024/赤道仪本体/340度限位盘 - DEC.SLDPRT
39.7 x 6.00 x 40.0 mm

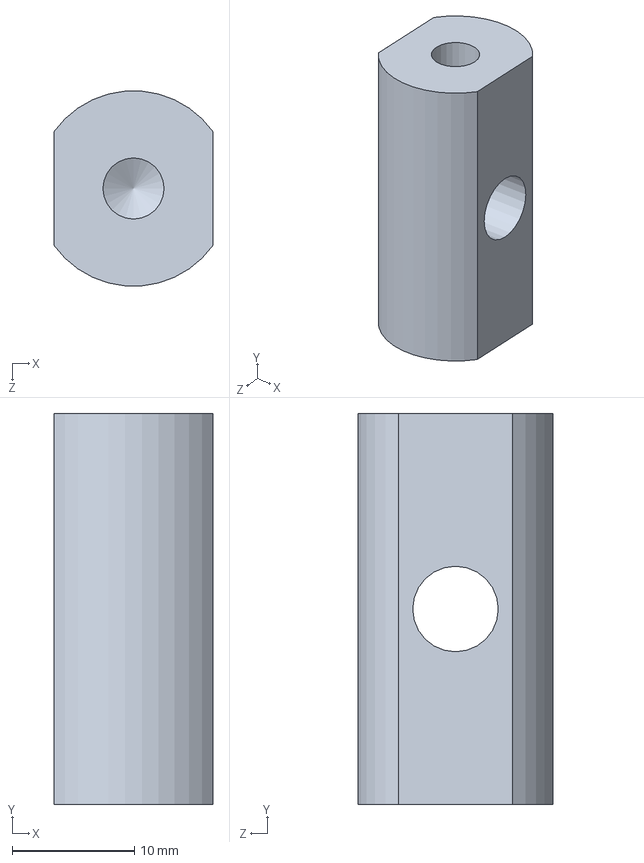
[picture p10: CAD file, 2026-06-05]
hardware/SW2024/纬度座/铜棒A.SLDPRT
13.0 x 32.0 x 15.9 mm

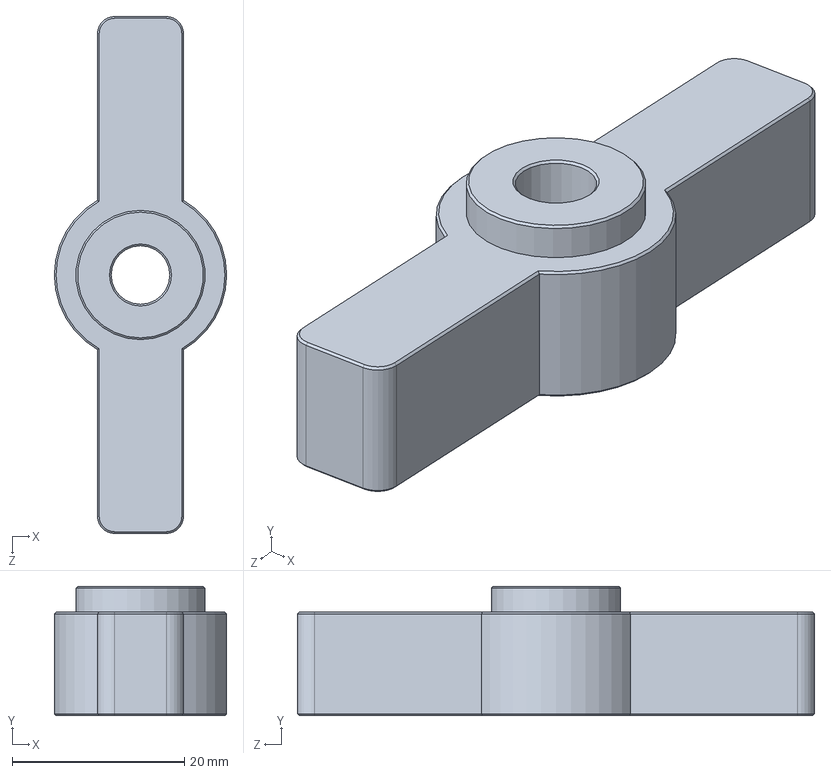
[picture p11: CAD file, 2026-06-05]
hardware/SW2024/纬度座/Thumbscrew Handle.SLDPRT
20.0 x 15.0 x 60.0 mm

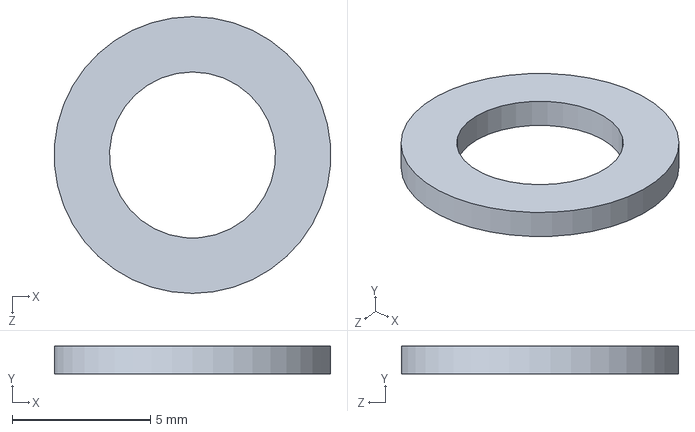
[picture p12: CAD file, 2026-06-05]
hardware/SW2024/纬度座/M6-10-1垫片.SLDPRT
9.97 x 1.00 x 10.0 mm

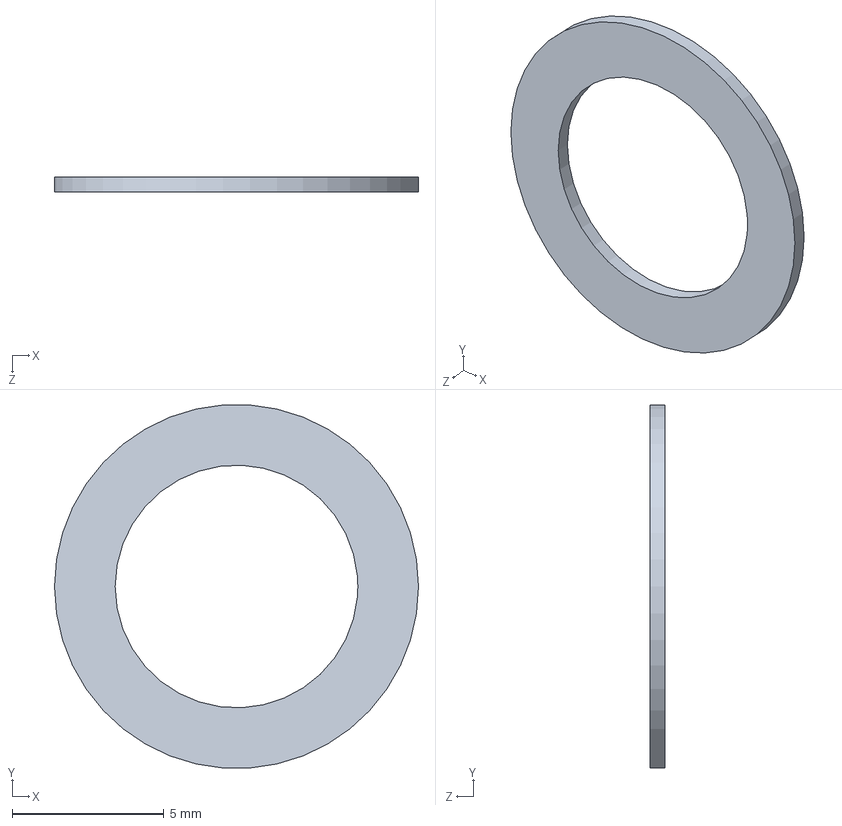
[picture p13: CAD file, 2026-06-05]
hardware/SW2024/纬度座/M8-12-0.5铜垫片.SLDPRT
12.0 x 12.0 x 0.5 mm

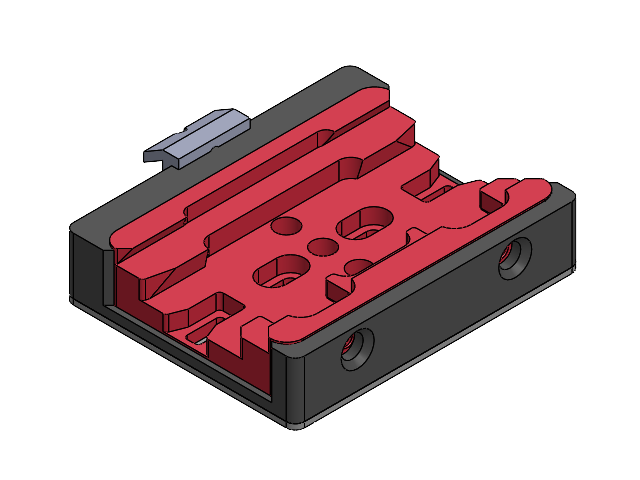
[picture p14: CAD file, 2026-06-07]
hardware/SW2024/赤道仪本体/组合体/鸠尾槽外壳+底板.SLDASM
鸠尾槽外壳
宽型鸠尾槽-2024
鸠尾槽外壳支撑铝板^鸠尾槽外壳+底板
桥式鸠尾槽

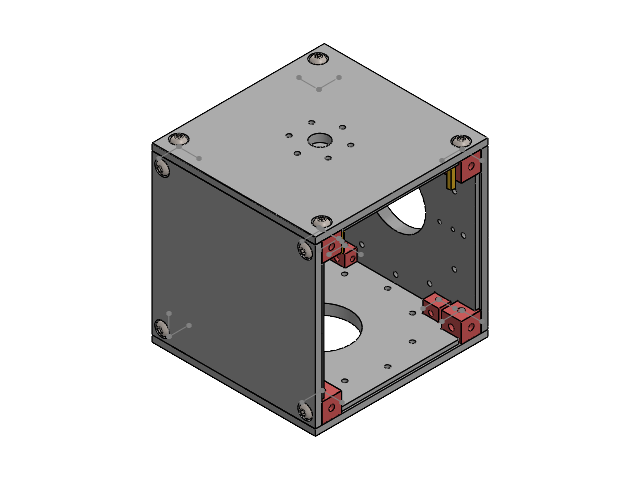
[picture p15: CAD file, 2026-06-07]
hardware/SW2024/赤道仪本体/组合体/25-100外壳.SLDASM
赤纬轴固定板
赤经轴固定板
固定板A
固定板B
15mm方形连接件 x 8
12mm方形连接件 x 2
hexagon socket button head screws gb x 20
主板铜柱 x 4

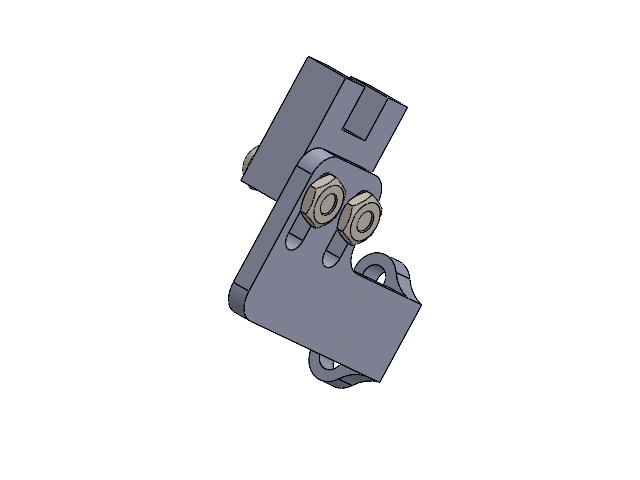
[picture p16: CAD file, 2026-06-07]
hardware/SW2024/赤道仪本体/组合体/原点传感器+固定座.SLDASM
光电传感器
光电传感器固定座B
hexagon socket button head screws gb x 2
hex thin nuts-grades ab-chamfered gb x 2

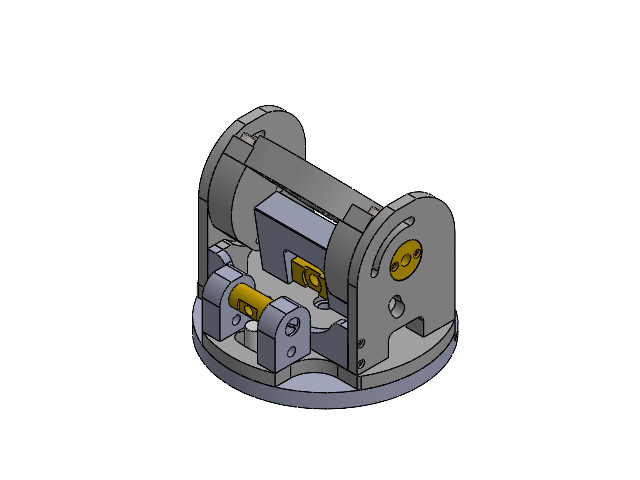
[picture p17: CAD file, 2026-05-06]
hardware/SW2024/纬度座/纬度座.SLDASM
固定盘
旋转盘
支撑臂A
RA法兰盘
连接轴A
连接轴B
法兰铜套 x 2
支撑臂B
圆柱销
俯仰调节A
俯仰调节B
铜棒A
连杆
铝合金推块
铝合金定位凸台
支撑板
hexagon socket head cap screws gb x 8
8-8-M6 x 2
8-10-M6 x 2
8-10-M6一字 x 2

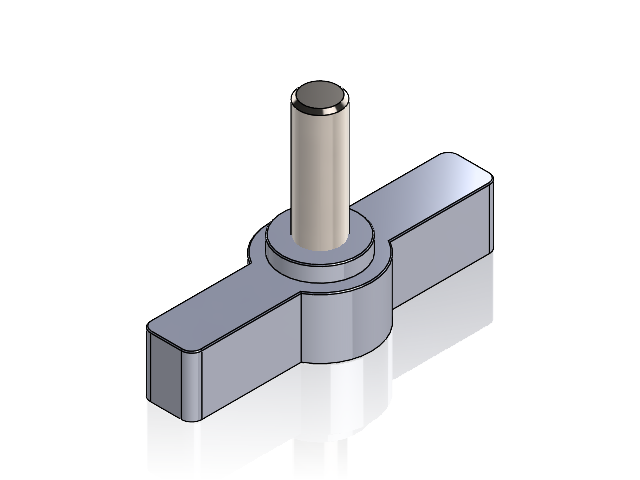
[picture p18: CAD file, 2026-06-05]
hardware/SW2024/纬度座/Thumb Screw.SLDASM
Thumbscrew Handle
socket head cap screw_am

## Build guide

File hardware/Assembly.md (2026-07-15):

<div align="center">
  
  
</div>

# 双25-100谐波赤道仪组装说明书

结合 `pictures/Assembly process` 目录下的实拍记录，分步讲解从机械结构到电控系统的完整拼装过程

## 🛠️ 准备工作与物料清单 (BOM)

在开始组装之前，请确保您已备齐以下核心零部件与工具(具体所需五金参考bom表)：

* **传动核心**：25-100型谐波减速器（1:100减速比）
* **惰轮**：2GT带宽10mm 80齿惰轮和2GT带宽10mm高19mm 20齿惰轮
* **电机与保护**：步进电机、掉电刹车（电磁阻尼/抱闸）模块
* **主控与驱动**：ESP32 + ESP07S 组合、TMC5160 步进电机驱动模块
* **电路底板**：定制设计的主控 PCB（支持 12V/24V 电源）
* **线材与辅料**：**电源开关引线**、各型号内六角螺丝、润滑脂、螺丝胶
*注：惰轮部分需要您有一定机加工能力对成品惰轮按照图纸中的规格进行改造，若无法改造，请自行修改模型以适配市面上的标准零件*
---

## 🖨️ 阶段一：3D打印与机加工准备
在正式组装之前，建议先完成以下准备工作：
1. **3D打印**：使用PETG—GF/CF材料打印所有需要的零件，确保打印质量和尺寸精度，特别是减速器保护罩，传动轴，传感器安装座等关键部件。

      **打印件清单：**
   
    | 序号 | 零件部位 | 对应源文件 |
    | :---: | :--- | :--- |
    | 1 | 主外壳 | `外壳.SLDPRT` |
    | 2 | 鸠尾槽外壳 | `鸠尾槽外壳.SLDPRT` |
    | 3 | 赤纬 / 赤经轴 | `DEC轴.SLDPRT` , `RA轴.SLDPRT` |
    | 4 | 鸠尾槽外壳 | `鸠尾槽外壳.SLDPRT` |
    | 5 | 控制板盖板 | `控制板盖板-插件.SLDPRT` |
    | 6 | 光电传感器固定座 | `光电传感器固定座A.SLDPRT`，`光电传感器固定座B.SLDPRT`，`光电传感器固定座B - 增高.SLDPRT` |

> 📷 *参考图片：*
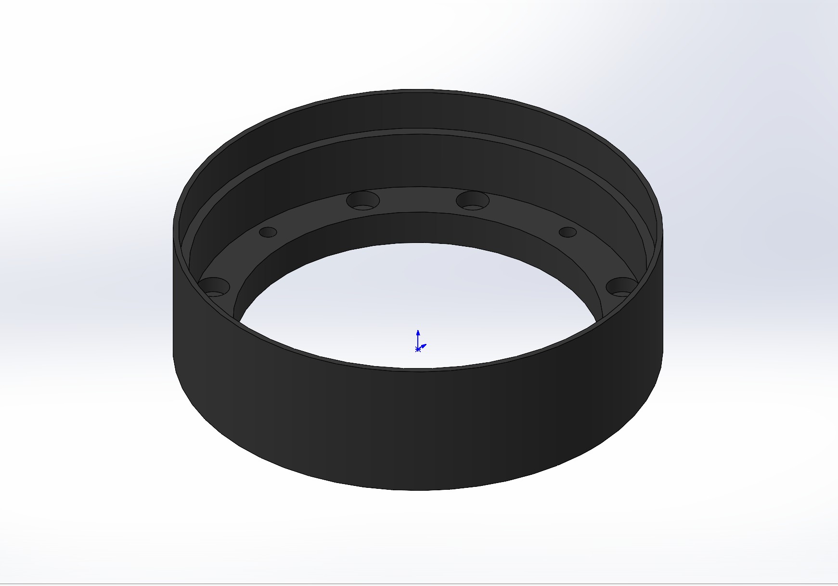
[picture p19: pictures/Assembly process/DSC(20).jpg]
> 
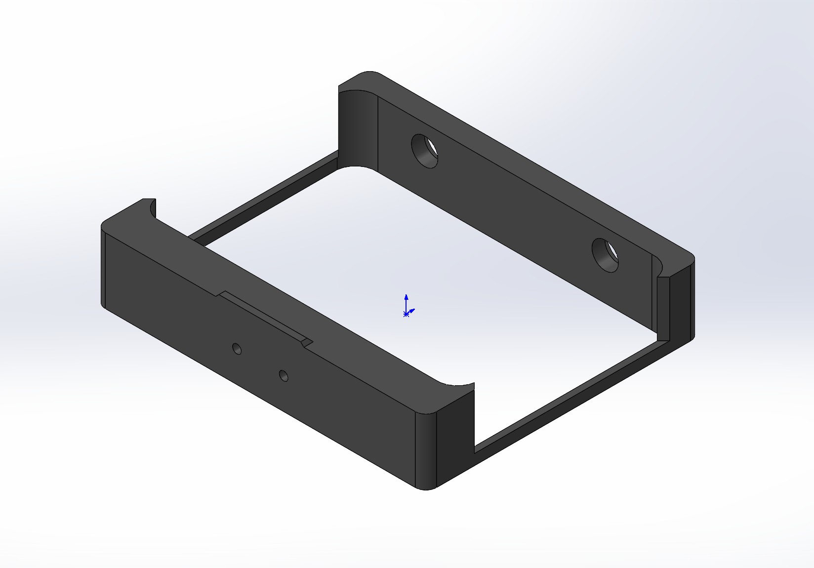
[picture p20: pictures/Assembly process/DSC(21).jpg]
> 
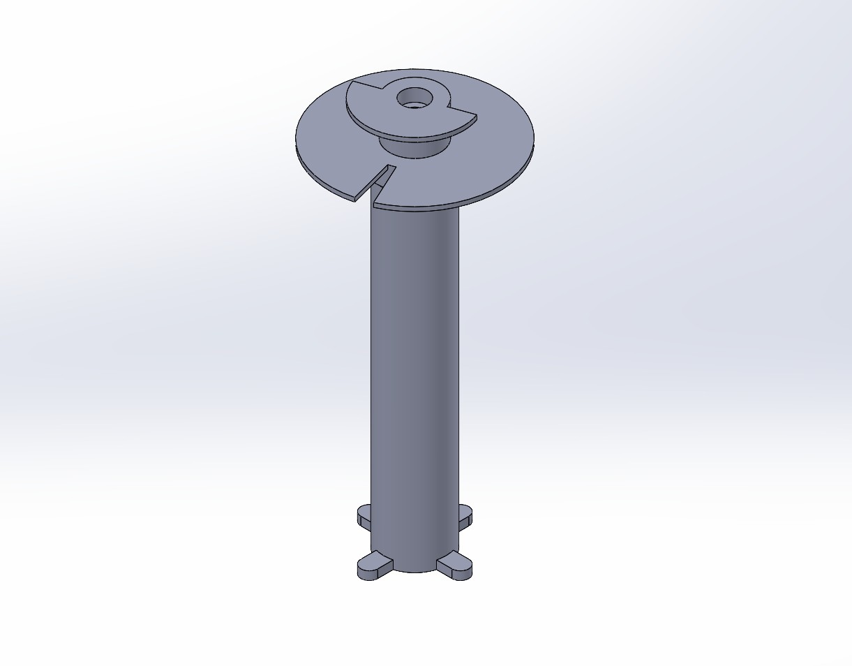
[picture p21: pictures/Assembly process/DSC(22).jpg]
> 

2. **给打印件熔入热熔螺母**：在组装前，先将准备好的热熔螺母熔入所有需要安装螺丝的3D打印件中，需要安装螺母的部位请参考下图中的标注，确保每个螺母都能牢固地固定在打印件中，并且位置准确，以便后续组装时能够顺利安装螺丝。

> 📷 *参考图片：*
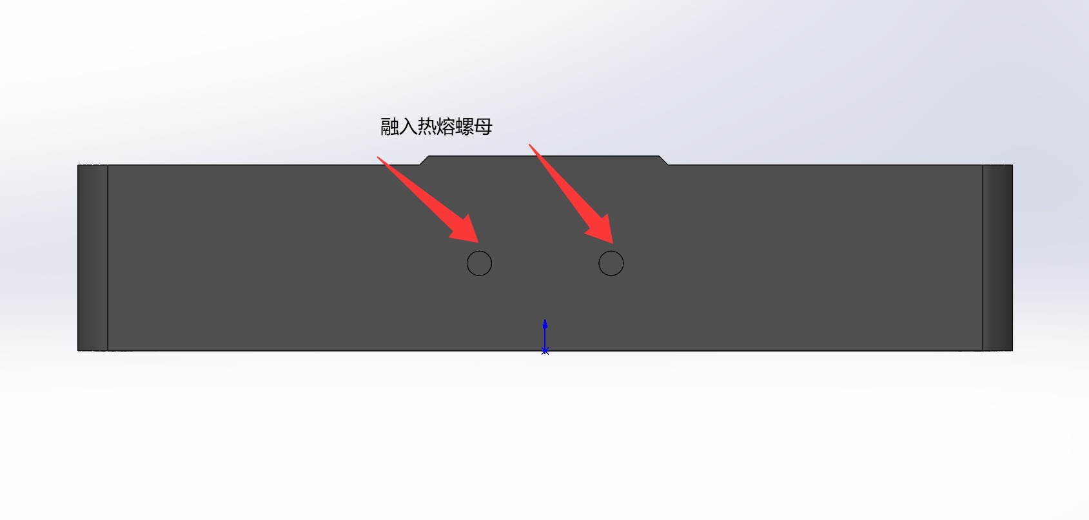
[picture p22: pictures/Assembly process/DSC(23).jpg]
> 
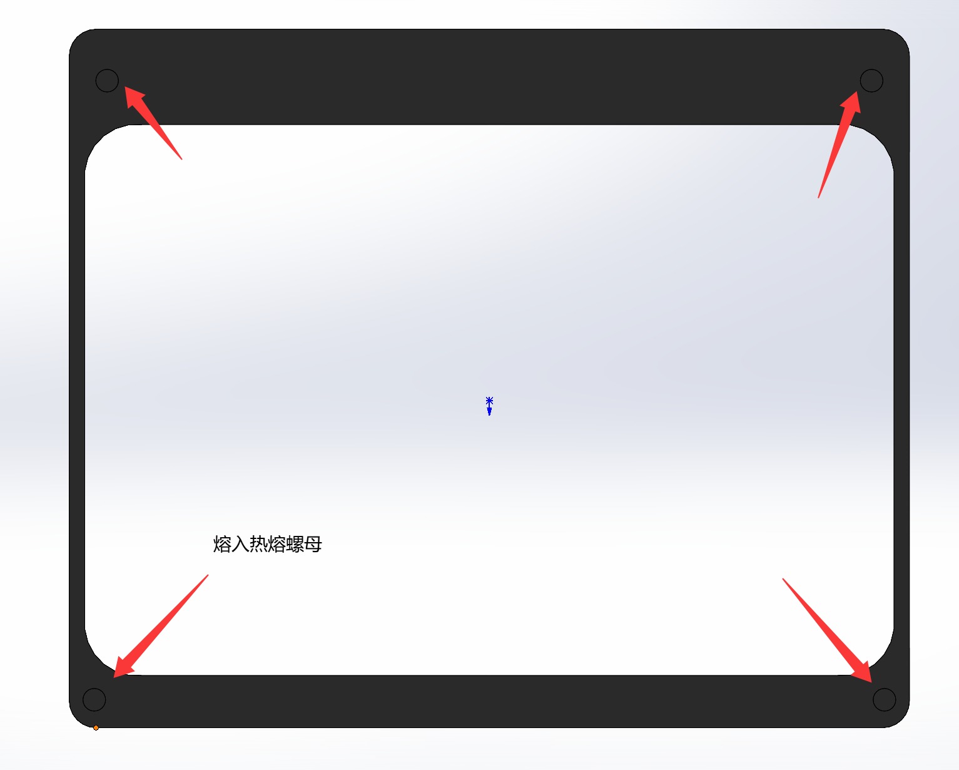
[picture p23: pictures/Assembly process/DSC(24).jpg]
> 
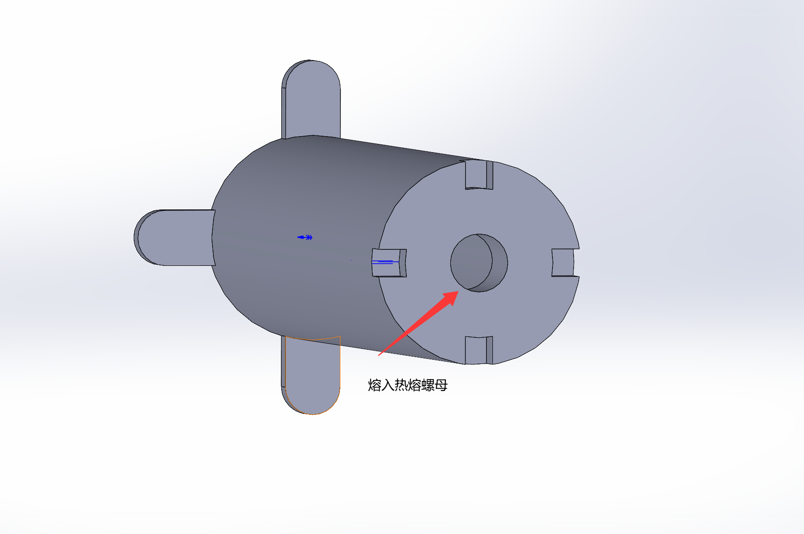
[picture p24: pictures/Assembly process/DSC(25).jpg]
> 
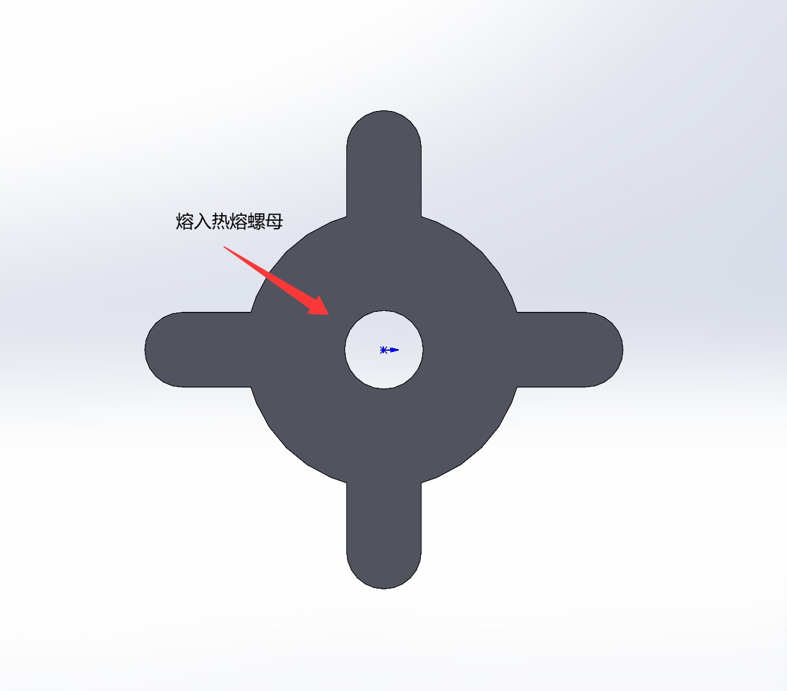
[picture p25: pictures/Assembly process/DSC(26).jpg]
> 

3. **机加工**：对惰轮进行必要的改造，确保其尺寸和安装孔位符合设计要求，同时对铝板进行钻孔和攻丝，准备好安装所需的螺丝和铜柱。

---

## ⚙️ 阶段二：机械结构组装

### 1. 谐波减速器的安装 (RA/DEC 轴)
在此步骤中，我们将安装赤道仪的核心部件，考虑到径向慢速旋转载荷的受力要求，安装时请务必保证法兰接触面的平整贴合

1.  将减速器法兰面与铝板螺孔精准对齐，尽可能的让铝板中心圆通孔与减速器中空轴同轴心，使用内六角螺丝并按对角线顺序均匀拧紧，确保减速器外壳受力均匀，避免因局部过紧导致的变形或过松引起的振动
2.  其中两个螺孔需要拧入更长的螺丝，且不需要拧上防松螺母以便后续电机座的安装
3.  其中有4个螺孔不需要拧入螺丝，以便后续安装3d打印的减速器保护罩
4.  将除去步骤2中的剩余的核心螺丝组件多余的部分拧入防松螺母，确保减速器与铝板之间的连接牢固且不会因振动而松动

> 📷 *参考图片：*
> 安装谐波减速器
> 安装谐波减速器
> 安装谐波减速器

### 2. 传动部分的组合
1.  将加工过的80齿轮2GT惰轮安装在减速器的输入轴上，确保惰轮与输入轴同轴心，使用内六角螺丝并按对角线顺序均匀拧紧，确保连接牢固且不会因振动而松动
2.  将20齿轮2GT惰轮安装在步进电机的输出轴上  
3.  将步进电机通过铜柱安装至电机座上
4.  **掉电刹车安装**：在用于RA轴的双出轴步进电机的尾端，替换原有电机的螺丝并安装电磁抱闸模块，能有效防止设备意外断电时由于重锤失衡导致的望远镜“磕头”受损
5.  提前将2GT带宽10mm同步带套在电机惰轮上，便于后续安装

> 📷 *参考图片：*
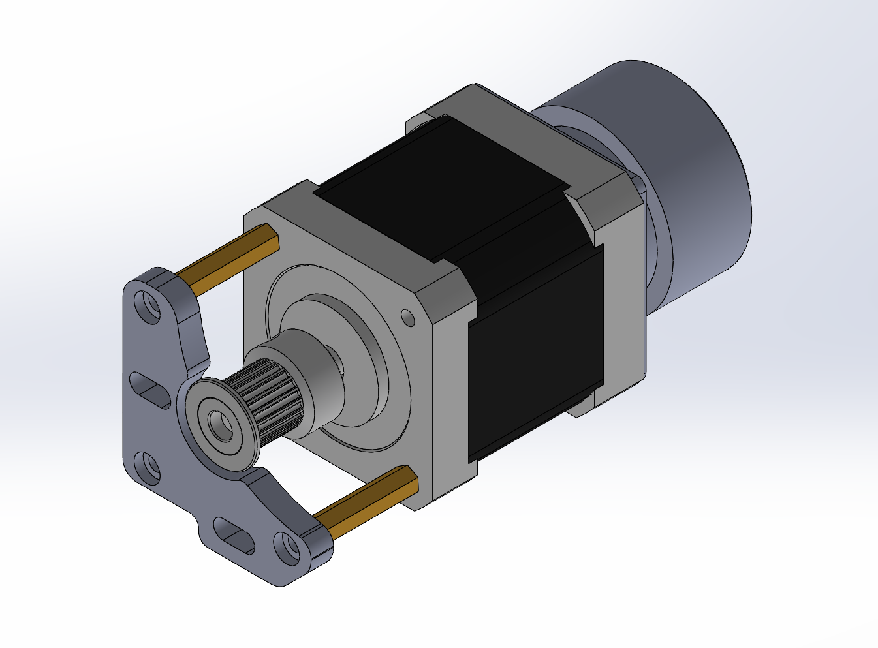
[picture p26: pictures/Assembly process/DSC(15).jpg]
> 
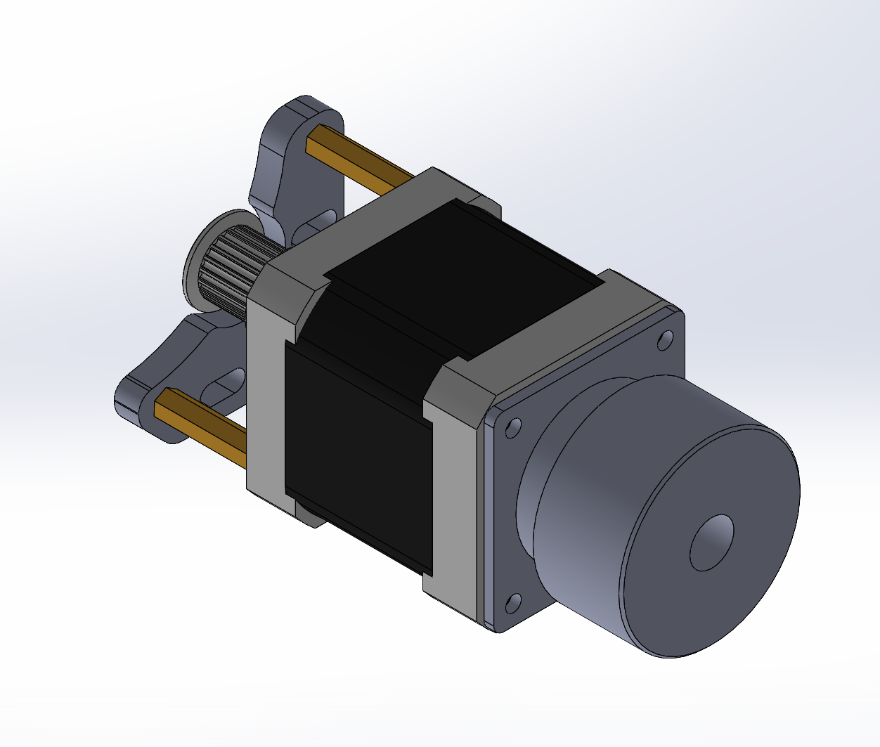
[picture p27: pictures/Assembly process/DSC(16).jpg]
> 
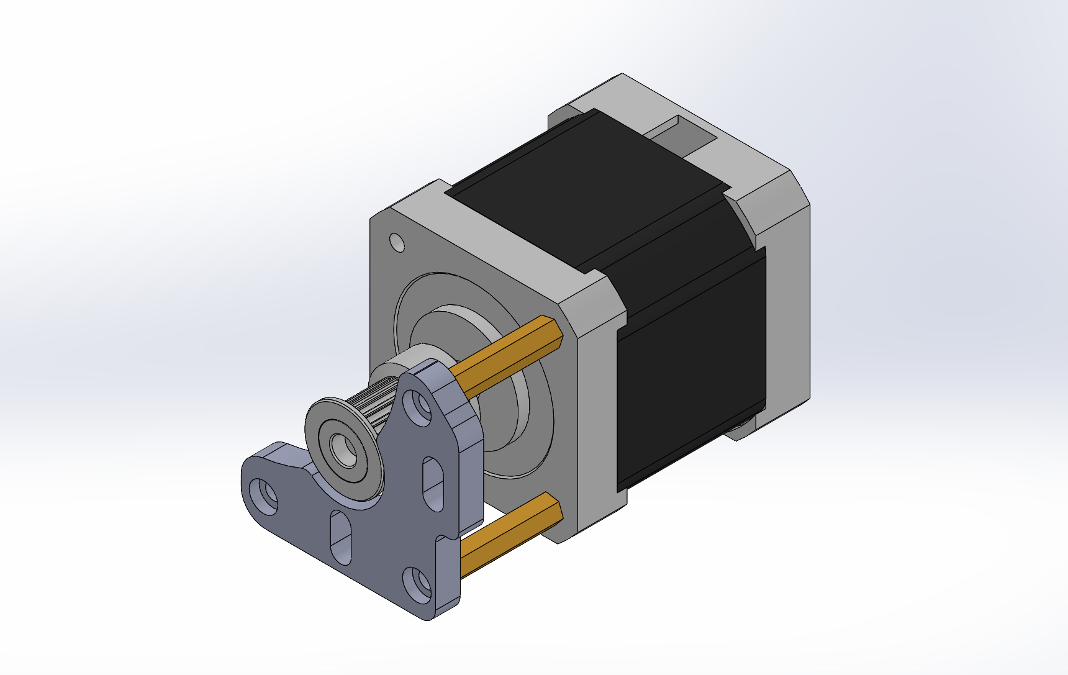
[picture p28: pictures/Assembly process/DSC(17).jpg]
DEC轴电机安装
> 

### 3. RA轴纬度座法兰的组装
1.  将RA轴法兰盘与连接轴A和连接轴B通过内六角螺丝连接
2.  在步骤1的过程中，同时组装推杆和推块结构，确保推杆能够在推块内顺畅滑动，并且连接轴A和连接轴B能够通过推杆实现相对运动
3.  将步骤1和2中组装好的整体结构通过内六角螺丝安装到谐波减速器的法兰盘上，在安装过程同时安装3d打印好减速器保护罩

> 📷 *参考图片：*
> 纬度座的组装
> 纬度座的组装
> 纬度座的组装

### 4. 电机，同步带与减速器的连接以及传感器，法兰盘的安装
1.  通过电机座上预留的孔位安装至步骤1中铝板上预留的更长螺丝上，绷紧同步带，并在螺丝上拧上防松螺母，确保同步带在传动过程中不会发生打滑或过度松弛
2.  并适当调整电机输出轴上的惰轮高度，使其与减速器输入轴上的惰轮处于同一水平面，确保同步带的张力均匀分布，避免因不平行导致的过度磨损或传动效率降低
3.  在完成上述步骤后，手动旋转大惰轮，检查同步带的运行是否平稳，确保没有异常的摩擦声或振动，这将有助于确认传动系统的正确安装和调整
4.  在完成安装后，建议在同步带上喷涂适量的矽质润滑剂，以减少摩擦和异响并延长同步带的使用寿命
5.  安装RA/DEC轴的光电传感器限位开关和原点开关，确保它们的位置能够准确检测到轴的极限位置和原点位置，以实现安全保护和精准定位
6.  将3d打印好的减速器保护罩安装在减速器外部，使用预留的螺孔和内六角螺丝固定，确保保护罩能够有效防止灰尘和杂物进入减速器，同时不干扰其正常运行
7.  安装RA/DEC轴的法兰盘，确保其与轴同轴心，并使用内六角螺丝均匀拧紧，确保法兰盘在运行过程中不会发生偏移或松动

> 📷 *参考图片：*
> RA轴电机与刹车模块，传感器，法兰盘的安装
> DEC轴电机，同步带
> DEC轴法兰盘的安装
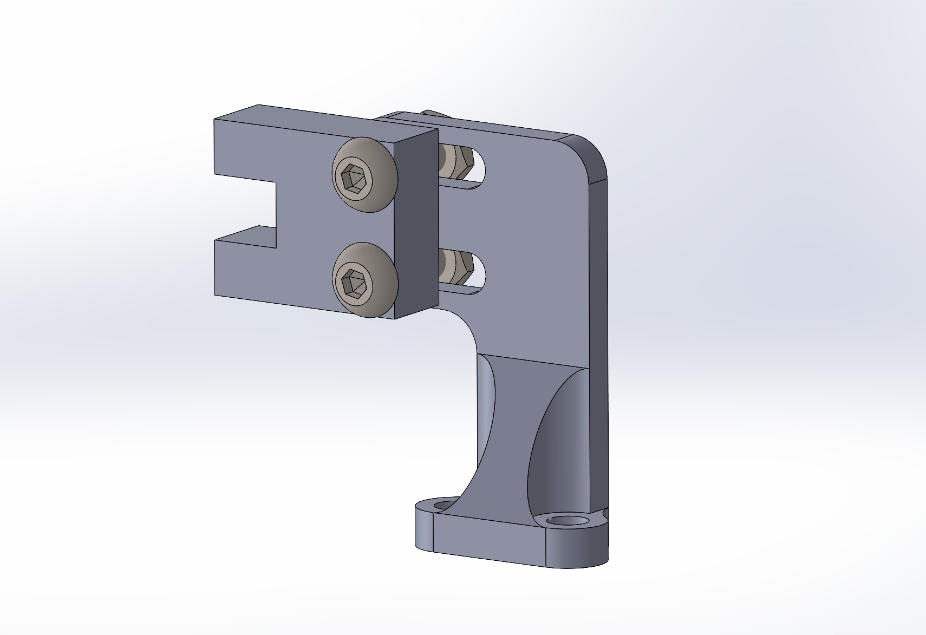
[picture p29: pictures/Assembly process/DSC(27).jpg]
> 
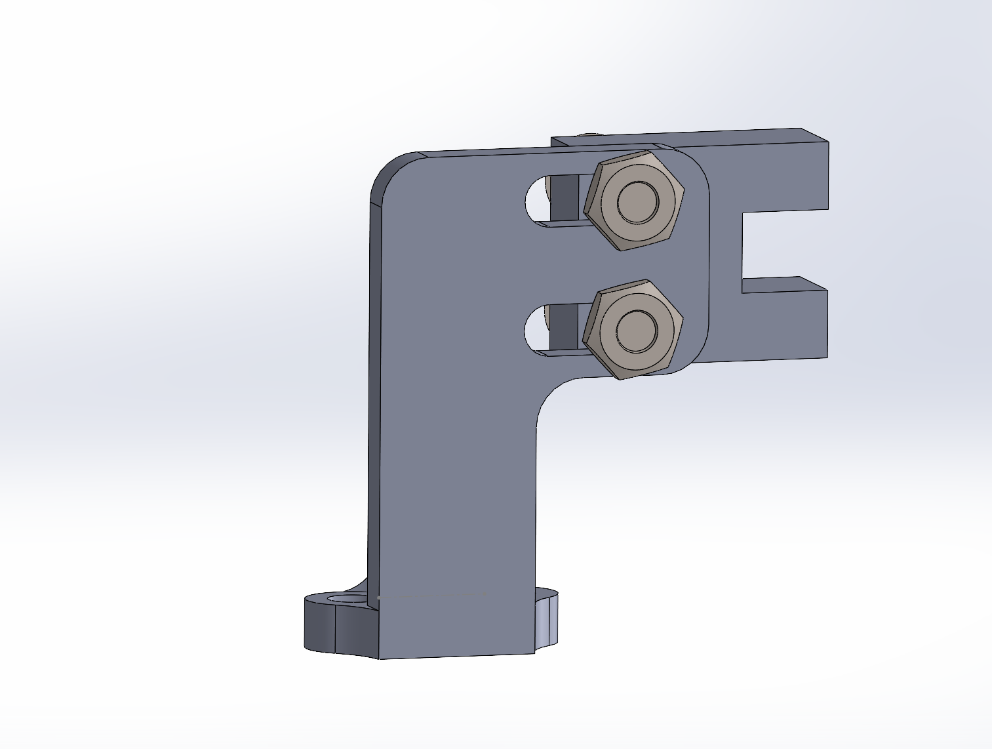
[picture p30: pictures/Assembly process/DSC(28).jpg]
> 
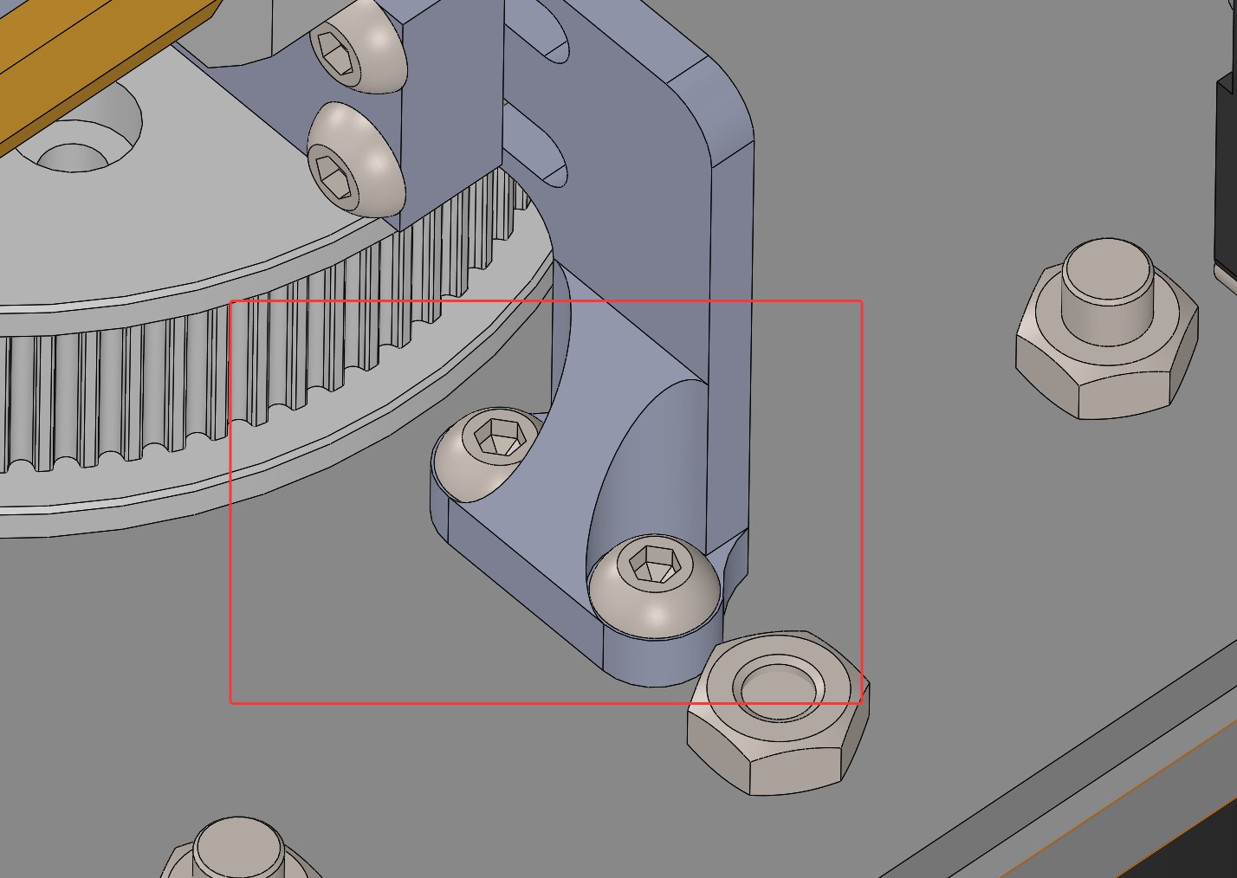
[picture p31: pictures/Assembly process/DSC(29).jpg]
> 

### 5. 外壳的组装
1.  将组装好RA轴和DEC轴的机械结构通过铝块连接，利用大理石水平面确保所有铝板都能够垂直正交安装并且不会发生干涉
2.  并在螺丝连接处涂抹适量的螺丝胶，确保在设备运行过程中机械连接的稳定性和可靠性

> 📷 *参考图片：*
> 外壳的组装

---

## ⚡ 阶段三：电控组装与走线

### 1. PCB 底板与驱动安装
1.  将制作好的 PCB 板通过铜柱固定在电控仓内部，安装时请仔细检查背面的 12V/24V 大电流电源平面，确保其与金属外壳之间有足够的绝缘距离。
2.  依次将 TMC5160 驱动模块和 ESP32 主控板插接至对应排母，注意核对引脚方向，切勿插反。

> 📷 *参考图片：*
> PCB及驱动安装
> PCB及驱动安装

### 2. 规范接线与理线
为保证设备在野外环境与大电流驱动下的绝对稳定，本项目的接线有着严格的要求：
1.  主电源线路必须使用标准的**电源开关引线**进行连接至 PCB。**严禁使用任何随意的“飞线”**作为电源通路的替代方案。
2.  将 RA 轴和 DEC 轴步进电机的控制线接入 TMC5160 对应的端子。
3.  连接掉电保护系统的控制线，并整理所有线束，确保赤道仪在全方位极限旋转时线缆不会发生缠绕或过度拉扯。

> 📷 *参考图片：*
> 规范的电源引线与内部走线

---

## 💻 阶段四：固件配置与初步调试

赤道仪的硬件逻辑专为标准的 OnStep 环境设计

1.  **固件选择**：系统运行的是**普通的 OnStep 固件**（⚠️请注意：本项目**不适用** OnStepX，切勿刷错固件版本）。
2.  **通讯确认**：确保 ESP32 的引脚映射与您修改好的 OnStep 固件相匹配，同时确认 ESP07S 的网络通讯连接正常。
3.  **上电自检**：接入电源，测试电磁抱闸是否能正常吸合/释放，并通过上位机监测 TMC5160 的运行状态及细分设置。

> 📷 *参考图片：*
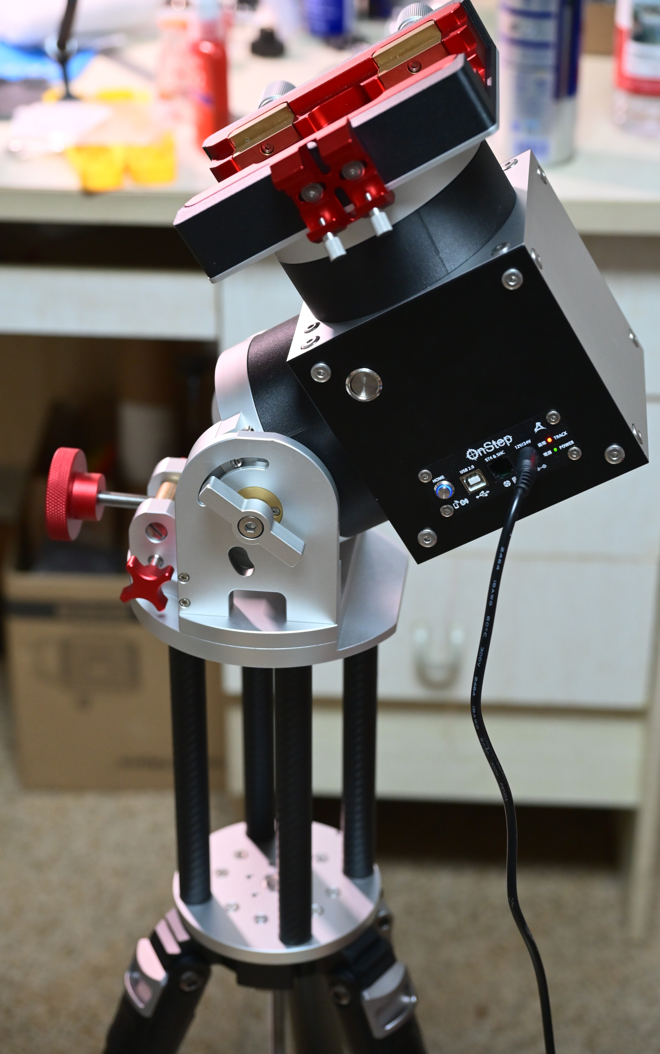
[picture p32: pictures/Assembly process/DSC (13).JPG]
> 
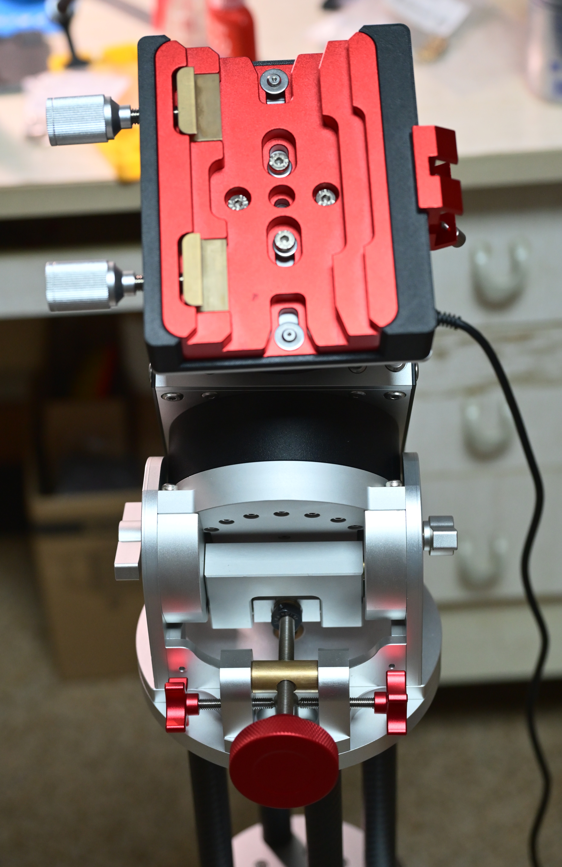
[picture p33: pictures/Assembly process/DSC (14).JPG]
> 

---

## 🤝 开源协议与贡献
如果您在组装过程中发现了可优化的机械公差或更好的布线方案，欢迎提交 Issue 或 Pull Request，本项目采用 `GPLv3 + CERN-OHL-S` 双开源协议，感谢您对开源天文硬件社区的贡献！

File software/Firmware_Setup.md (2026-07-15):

<div align="center">
  
  
</div>

谐波赤道仪主控采用 **ESP32-WROOM-32E16N（16MB 闪存版）** 这款大容量核心能够稳定运行复杂的 [OnStep / OnStepX](https://onstep.groups.io/g/main/wiki) 固件

## ⚙️ 编译环境与主板设置（至关重要）

由于本项目使用的是 16MB 版本 ESP32，**请不要使用默认的 4MB 编译设置**，否则可能导致固件编译失败，或无法充分利用可用闪存空间以下流程基于 Arduino IDE，同样适用于需要修改 `platformio.ini` 的 PlatformIO 用户

1. **准备环境**：下载最新版 Arduino IDE，在“首选项”中添加 ESP32 开发板管理器网址，并安装 ESP32 支持包（建议使用 2.0.0 版本以获得较好的兼容性）
2. **选择主板**：在 `工具 (Tools)` -> `开发板 (Board)` 中选择 **ESP32 Dev Module**
3. **关键参数配置**（请严格按照以下设置）：
   * **Flash Size（闪存大小）**：选择 `16MB (128Mb)`
   * **Partition Scheme（分区方案）**：选择适合 OnStep 的方案，例如 `16M Flash (3MB APP/9.9MB FATFS)` 或 `Huge APP`，以确保有足够空间存放 OnStep 的核心代码
   * **PSRAM**：如果模块带有 PSRAM，请设为 `Enabled`；标准 32E 模块请保持 `Disabled`
   * **Upload Speed（上传速度）**：选择 `921600`；如遇上传不稳定，可降至 `460800`

## 📝 Config.h 核心参数适配

正式刷写前，需要在 OnStep 源码中修改 `Config.h`，使其精确适配当前硬件可参考模板文件 `Config-5160.h` 和 `Config-2209.h`

**💡 提示：如果您复刻的机械结构与本项目完全一致，包括电机和谐波减速器规格，相关参数可以直接复制使用**

* **引脚映射 (Pinmap)**：找到并启用与本定制 PCB 匹配的引脚定义方案，确保通讯走线、步进脉冲接口（STEP/DIR）以及限位开关等接口映射正确
* **每度步数配置 (Steps per Degree)**：
  * 核心计算公式：`(电机每圈物理步数 × 细分数 × 总减速比) / 360`
  * 以标准 1.8° 步进电机（每圈 200 步）和 1:100 的 25 规格谐波减速器为例，具体数值取决于所使用的驱动器模式

* **模式 A：TMC5160 SPI 智能模式（推荐 🚀）**：
  * **驱动器型号**：将赤经轴（RA）和赤纬轴（Dec）严格定义为 `TMC5160_SPI`
  * **细分设置**：建议设为 **64** 或 **128**TMC 会在底层自动插值到 256 微步，以获得更平滑的恒星跟踪效果
  * **参数示例**：若使用 64 细分，计算结果为 `(200 × 64 × 100) / 360 ≈ 3555.556`请将 `3555.556` 填入 `AXIS1_STEPS_PER_DEGREE` 和 `AXIS2_STEPS_PER_DEGREE`

* **模式 B：传统 STEP/DIR 模式（向下兼容 🔌）**：
  * **驱动器型号**：如果通过跳线断开 SPI，并使用 A4988、DRV8825 或独立模式的 TMC 驱动器，请将驱动型号修改为对应类型，例如 `A4988` 或 `GENERIC`
  * **细分严格匹配**：⚠️ 固件中的 `AXIS_MICROSTEPS` **必须严格等于**主板跳线帽设定的物理细分值传统 STEP/DIR 模式下，固件无法动态修改细分
  * **参数示例**：若物理跳线设为 32 细分，计算结果为 `(200 × 32 × 100) / 360 ≈ 1777.778`请将该数值填入对应的步数参数
  * **⚡ 电流设置（手动调节）**：传统模式下，OnStep 无法通过软件控制电流请在主板通电状态下使用万用表测量，并使用陶瓷十字螺丝刀极其缓慢地旋转驱动器模块上的电位器，以设定 VREF 参考电压**操作时务必小心，避免短路！**

### 🚀 刷写固件与上传 Web UI

OnStep 在 ESP32 平台上的完整安装包含**两个独立步骤**：上传核心固件和上传文件系统两者缺一不可以下流程以使用 TMC5160 驱动为例

## 第一步：上传 OnStep 核心固件

1. 使用优质数据线连接主控板系统通讯依赖板载 CP2102GMR 芯片，请确保已安装 Silicon Labs 官方驱动
2. 在 IDE 中选择对应的 COM 端口，点击“上传 (Upload)”
3. 先在 `Config.h` 中关闭 SPI 通讯模式，以避免因本 PCB 共用 I/O 口而导致报错，并为后续刷写 ESP07S 做准备
   * *注：如果终端出现 `Connecting...` 超时，请按住 PCB 上的 `BOOT` 按钮，直到上传进度条出现*

## 第二步：上传 Smart Web Server

通过 Wi-Fi 控制 OnStep 依赖存储在 ESP07S 闪存中的网页文件由于 PCB 设计紧凑，没有为 ESP07S 预留独立刷写通道，因此需要将 ESP32 作为转发桥梁来完成 ESP07S 固件刷写

* *注：刷写 ESP32 时，需要在 `Config.h` 中打开 `#define SERIAL_B_ESP_FLASHING` 功能，关闭 SPI 通讯模式（共用io若不先关闭会导致编译报错），并使用跳线帽连接 PCB 上对应的 RST 针脚*

---

## 📡 ESP32 透传刷写 ESP07S（SmartWebServer）指南

请严格按照以下顺序操作任何步骤错误都可能导致刷写失败如果复刻结构与本项目完全一致，相关参数可以直接复制使用

**🛠️ 第一阶段：准备工作**

为了使用命令行工具进行刷写，不能直接上传源码，需要先生成 `.bin` 格式的固件文件，并准备对应的刷写工具

**1. 准备 WiFi 固件文件 (`.bin`)**

1. 在 Arduino IDE 中打开 ESP8266 WiFi（SmartWebServer）源码
2. 在 **工具 (Tools) -> 开发板 (Board)** 中选择 **`LOLIN (WeMos) D1 R2 & mini`**
3. 点击菜单栏：**项目 (Sketch) -> 导出已编译的二进制文件 (Export Compiled Binary)**
4. 在源码文件夹中找到刚刚生成的 `.bin` 文件，选择文件名最短的版本，例如 `SmartWebServer.bin`
5. 将该文件复制到 `D 盘` 根目录，并改成简单文件名，例如 `wifi.bin`

**2. 准备刷写工具 (`esptool`)**

需要准备 Python 环境下的 `esptool.py`，或编译好的独立程序 `esptool.exe`

* **如果已经安装 Python**：打开 CMD 命令提示符，输入 `pip install esptool` 即可完成安装
* **如果没有安装 Python**：在 Arduino 安装目录中搜索 `esptool.exe`，并将其复制到 `D 盘` 根目录备用

**🚀 第二阶段：操作流程**

**第一步：建立透传通道**

1. 将包含 ESP32 的主控板通过 USB 连接至电脑
2. 打开 Arduino 的 **串口监视器 (Serial Monitor)**
3. 在发送框输入 `:ESPFLASH#`，然后点击发送
4. **关键检查**：此时 OnStep 会根据预先定义的引脚自动拉低 IO26（WiFi IO0），随后拉低再拉高 IO2（WiFi RST）如果这一步成功，ESP07S 应已进入“等待刷写”状态
5. 🛑 **关闭串口监视器！** 这一步极其重要，必须释放 COM 口供下一步 `esptool` 使用

**第二步：执行“无复位”刷写指令**

打开电脑的 CMD（命令提示符），根据准备的工具输入以下命令示例假设文件位于 D 盘，端口为 `COM7`，请按实际情况修改

**选项 A：使用 `esptool.exe`（Windows 独立程序）**

先输入 `D:` 并回车，切换到 D 盘，然后执行：

```bash
esptool.exe -p COM7 -b 115200 --before no_reset write_flash 0x00000 wifi.bin
```

**选项 B：使用 Python 的 `esptool.py`**

直接在 CMD 中执行：

```bash
python -m esptool -p COM7 -b 115200 --before no_reset write_flash 0x00000 D:\wifi.bin
```

* *注：刷写完成后即可取下跳线帽*

## 第三步：重新上传 OnStep 核心固件

1. 在 `Config.h` 中重新打开 SPI 通讯模式，并关闭 `#define SERIAL_B_ESP_FLASHING`
2. 在 IDE 中选择对应的 COM 端口，点击“上传 (Upload)”重新刷写
3. 完成以上步骤后，即可完成刷写并投入使用

---

### 🔍 参数详解

* **`-p COM7`**：指定连接硬件的端口
* **`-b 115200`**：**必须使用低速！** 软件透传无法承受 921600 等高速波特率，主控软串口转发时容易丢包
* **`--before no_reset`**：**核心参数** 它告诉电脑“直接发送数据，不要尝试重启 ESP32”，这样主控 ESP32 才能保持在透传模式，并将数据转发给 ESP07S
* *(如果使用 PlatformIO，请点击左侧蚂蚁图标，运行 `Upload File System image` 任务)*

> ⚠️
> **初始启动与安全校验：** 刷写完成后，主控板首次启动会建立一个名为 `OnStep` 的 Wi-Fi 热点（默认密码通常为 `password`）连接后，在浏览器中输入 `192.168.0.1` 即可进入控制面板**强烈建议：** 在挂载昂贵的望远镜之前，务必先进行空载测试，仔细验证 TMC5160 驱动器电流设置、电机运转方向，以及限位开关 (Limit Switches) 的触发状态，确保高扭矩谐波减速器不会对机械结构造成损坏

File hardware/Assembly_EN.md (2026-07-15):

<div align="center">
  
  
</div>

# Dual 25-100 Harmonic Equatorial Mount Assembly Instructions

Combining real-life footage from the `pictures/Assembly process` directory, this guide explains the complete assembly process, from the mechanical structure to the electrical control system, step-by-step.

## 🛠️ Preparation and Materials List (BOM)

Before starting assembly, please ensure you have the following core components and tools ready (refer to the BOM for specific hardware requirements):

* **Transmission Core**: 25-100 type harmonic reducer (1:100 reduction ratio)
* **Idler Gears**: 2GT 10mm wide 80-tooth idler gear and 2GT 10mm wide 19mm high 20-tooth idler gear
* **Motor and Protection**: Stepper motor, power-off brake (electromagnetic damping/holding brake) module
* **Main Control and Drive**: ESP32 + ESP07S combination, TMC5160 stepper motor drive module
* **Circuit Board**: Custom-designed main control PCB (supports 12V/24V power supply)
* **Wires and Accessories:** Power switch leads, various types of Allen screws, lubricant, and screw glue.

*Note: For the idler gear, you need some machining skills to modify the finished idler gear according to the specifications in the drawings. If you cannot modify it, please modify the model to fit standard parts available on the market.*

---

## 🖨️ Phase One: 3D Printing and Machining Preparation

Before formal assembly, it is recommended to complete the following preparations:

1. **3D Printing:** Use PETG-GF/CF material to print all necessary parts, ensuring print quality and dimensional accuracy, especially for key components such as the reducer protective cover, drive shaft, and sensor mounting bracket.

      **Printed Parts List:**

    | Item No. | Part Location | Corresponding Source File |
    | :---: | :--- | :--- |
    | 1 | Main Housing | `Housing.SLDPRT` |
    | 2 | Dovetail Slot Housing | `Dovetail Slot Housing.SLDPRT` |
    | 3 | Declination / Right Ascension Axis | `DEC Axis.SLDPRT` , `RA Axis.SLDPRT` |
    | 4 | Dovetail Slot Housing | `Dovetail Slot Housing.SLDPRT` |
    | 5 | Control Board Cover | `Control Board Cover - Insert.SLDPRT` |
    | 6 | Photoelectric Sensor Mount | `Photoelectric Sensor Mount A.SLDPRT`, `Photoelectric Sensor Mount B.SLDPRT`, `Photoelectric Sensor Mount B - Heightening.SLDPRT` |

> 📷 *Reference Image:*
> 3D Printed Parts
> 3D Printed Parts
> 3D Printed Parts

2. **Fuse Hot-Melt Nuts into Printed Parts:** Before assembly, fuse the prepared hot-melt nuts into all 3D printed parts that require screws. Refer to the markings in the image below for the locations where nuts will be installed. Ensure each nut is securely fixed in the printed part and accurately positioned for easy screw installation during subsequent assembly.

> 📷 *Reference Images:*
> Installing the Hot Melt Nut
> Installing the Hot Melt Nut
> Installing the Hot Melt Nut Installing the thermoplastic nut

3. **Machining**: Modify the idler wheel as necessary to ensure its dimensions and mounting hole positions meet design requirements. Simultaneously, drill and tap holes in the aluminum plate, preparing the necessary screws and copper posts for installation.

---

## ⚙️ Phase Two: Mechanical Structure Assembly

### 1. Harmonic Reducer Installation (RA/DEC Axis)
In this step, we will install the core components of the equatorial mount. Considering the stress requirements of the radial slow-speed rotating load, please ensure that the flange contact surfaces are flat and in close contact during installation.

1. Precisely align the reducer flange face with the screw holes on the aluminum plate, making the center through hole of the aluminum plate as coaxial as possible with the hollow shaft of the reducer. Use hex socket head cap screws and tighten them evenly in a diagonal sequence to ensure uniform stress on the reducer housing and avoid deformation caused by excessive tightness or vibration caused by excessive looseness.
2. Two screw holes require longer screws, and lock nuts are not needed for subsequent motor mount installation.
3. Four screw holes do not require screws for subsequent installation of the 3D-printed reducer protective cover.
4. Tighten the excess parts of the remaining core screw components (excluding those from step 2) into lock nuts to ensure a secure connection between the reducer and the aluminum plate that will not loosen due to vibration.

> 📷 *Reference Images:*
> Installing Harmonic Reducer
> Installing Harmonic Reducer
> Installing Harmonic Reducer

### 2. Transmission Assembly

1. Install the machined 80-gear 2GT idler wheel onto the input shaft of the reducer, ensuring the idler wheel is coaxial with the input shaft. Use Allen screws and tighten them evenly in a diagonal sequence to ensure a secure connection that will not loosen due to vibration.
2. Install the 20-gear 2GT idler wheel onto the output shaft of the stepper motor.
3. Mount the stepper motor onto the motor mount using copper pillars.
4. **Power-off Brake Installation**: Replace the original motor screws at the tail end of the dual-output-axis stepper motor used for the RA axis and install an electromagnetic brake module. This effectively prevents damage to the telescope's "head" due to counterweight imbalance during unexpected power outages.
5. Place a 2GT 10mm wide synchronous belt onto the motor idler wheel beforehand for easier subsequent installation.

> 📷 *Reference Image:*
> RA Axis Motor and Brake Module Installation
> RA Axis Motor and Brake Module Installation
> DEC Axis Motor Installation

### 3. Assembly of RA Axis Latitude Seat Flange
1. 1. Connect the RA shaft flange to connecting shafts A and B using hex socket screws.
2. During step 1, simultaneously assemble the push rod and push block structure, ensuring the push rod can slide smoothly within the push block, and that connecting shafts A and B can achieve relative movement via the push rod.
3. Install the assembled structure from steps 1 and 2 onto the flange of the harmonic reducer using hex socket screws. Simultaneously install the 3D-printed reducer protective cover during the installation process.

> 📷 *Reference Image:*
> Assembly of Latitude Mount
> Assembly of Latitude Mount
> Assembly of Latitude Mount

### 4. Connection of Motor, Synchronous Belt and Reducer, and Installation of Sensor and Flange

1. Install the motor onto the longer screws pre-drilled on the aluminum plate in step 1 through the pre-drilled holes on the motor mount. Tighten the synchronous belt and tighten the anti-loosening nuts on the screws to ensure that the synchronous belt does not slip or become excessively loose during transmission.
2. Adjust the height of the idler pulley on the motor output shaft appropriately so that it is on the same horizontal plane as the idler pulley on the reducer input shaft. This ensures even tension distribution of the synchronous belt and avoids excessive wear or reduced transmission efficiency due to non-parallelism.
3. After completing the above steps, manually rotate the large idler pulley to check if the synchronous belt runs smoothly and ensure there are no abnormal friction sounds or vibrations. This will help confirm the correct installation and adjustment of the transmission system.
4. After installation, it is recommended to spray an appropriate amount of silicone lubricant on the synchronous belt to reduce friction and abnormal noise and extend the service life of the synchronous belt.
5. Install the photoelectric sensor limit switches and origin switches on the RA/DEC shafts to ensure that their positions can accurately detect the extreme positions and origin positions of the shaft for safety protection and precise positioning.
6. Install the 3D-printed reducer protective cover on the outside of the reducer, using the pre-drilled screw holes and hex socket screws for fixing. This ensures that the protective cover can effectively prevent dust and debris from entering the reducer without interfering with its normal operation.
7. Install the flange of the RA/DEC shaft, ensuring it is coaxial with the shaft, and tighten it evenly with Allen screws to ensure the flange does not shift or loosen during operation.

> 📷 *Reference Image:*
> RA shaft motor and brake module, sensor, flange installation Installation of RA axis motor, brake module, sensor, and flange
> DEC axis motor, timing belt
> DEC axis flange installation
> Sensor Installation
> Sensor Installation
> Sensor Installation

### 5. Housing Assembly
1. Connect the assembled RA and DEC axes mechanical structures using aluminum blocks. Utilize a marble-like horizontal surface to ensure all aluminum plates are installed perpendicularly and orthogonally without interference.
2. Apply an appropriate amount of screw glue to the screw connections to ensure the stability and reliability of the mechanical connections during equipment operation.

> 📷 *Reference Image:*
> Shell Assembly

---

## ⚡ Phase Three: Electrical Control Assembly and Wiring

### 1. PCB Base Plate and Driver Installation

1. Fix the assembled PCB board inside the electrical control compartment using copper pillars. During installation, carefully check the 12V/24V high-current power supply plane on the back to ensure sufficient insulation distance between it and the metal casing. 2. Connect the TMC5160 driver module and the ESP32 main control board to the corresponding female connectors in sequence, carefully checking the pin orientation to ensure they are correctly connected.

> 📷 *Reference Images:*
> PCB and Driver Installation
> PCB and Driver Installation

### 2. Standard Wiring and Cable Management To ensure the absolute stability of the equipment in outdoor environments and under high current driving conditions, the wiring in this project has strict requirements:

1. The main power supply line must use standard **power switch leads** to connect to the PCB. **The use of any arbitrary "flying wires"** as a substitute for the power path is strictly prohibited.
2. Connect the control cables for the RA and DEC axis stepper motors to the corresponding terminals on the TMC5160.
3. Connect the control cables for the power-off protection system and tidy up all wiring harnesses to ensure that the cables do not become tangled or excessively stretched during the equatorial mount's extreme rotation.

> 📷 *Reference Image:*
> Standard Power Leads and Internal Routing

---

## 💻 Phase Four: Firmware Configuration and Initial Debugging

The equatorial mount's hardware logic is designed specifically for the standard OnStep environment.

1. **Firmware Selection**: The system runs **standard OnStep firmware** (⚠️Please note: This project **does not apply** OnStepX; do not flash the wrong firmware version).
2. **Communication Confirmation**: Ensure the ESP32 pin mapping matches your modified OnStep firmware, and confirm the ESP07S's network communication connection is normal. 3. **Power-on Self-Test:** Connect to power and test whether the electromagnetic brake can engage/release normally. Monitor the operating status and microstepping settings of the TMC5160 via the host computer.

> 📷 *Reference Images:*
> Electronic Control System Lighting and Online Testing
> Electronic Control System Lighting and Online Testing

---

## 🤝 Open Source License and Contributions

If you find any optimizable mechanical tolerances or better wiring solutions during the assembly process, please submit an Issue or Pull Request. This project uses `GPLv3 + CERN-OHL-S` Dual open-source license, thank you for your contributions to the open-source astronomical hardware community!

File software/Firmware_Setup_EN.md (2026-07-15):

<div align="center">
  
  
</div>

The harmonic equatorial mount controller uses an **ESP32-WROOM-32E16N (16MB flash version)**. This high-capacity module can reliably run the complex [OnStep / OnStepX](https://onstep.groups.io/g/main/wiki) firmware.

## ⚙️ Compilation Environment and Board Settings (Critical)

Because this project uses the 16MB version of the ESP32, **do not use the default 4MB compilation settings**, otherwise firmware compilation may fail, or the available flash space may not be fully utilized. The following procedure is based on the Arduino IDE and also applies to PlatformIO users who need to modify `platformio.ini`.

1. **Prepare the environment**: Download the latest Arduino IDE, add the ESP32 board manager URL in “Preferences”, and install the ESP32 support package (version 2.0.0 is recommended for better compatibility)
2. **Select the board**: Select **ESP32 Dev Module** under `Tools` -> `Board`
3. **Configure the key parameters** (strictly follow the settings below):
   * **Flash Size**: Select `16MB (128Mb)`
   * **Partition Scheme**: Select a scheme suitable for OnStep, such as `16M Flash (3MB APP/9.9MB FATFS)` or `Huge APP`, to ensure there is enough space for the OnStep core code
   * **PSRAM**: If the module includes PSRAM, set it to `Enabled`; keep it `Disabled` for the standard 32E module
   * **Upload Speed**: Select `921600`; if uploading is unstable, reduce it to `460800`

## 📝 Config.h Core Parameter Configuration

Before flashing, modify `Config.h` in the OnStep source code so that it precisely matches the current hardware. Refer to the template files `Config-5160.h` and `Config-2209.h`.

**💡 Tip: If the mechanical structure you reproduced is identical to this project, including the motor and harmonic reducer specifications, the relevant parameters can be copied directly.**

* **Pinmap**: Find and enable the pin definition scheme that matches this custom PCB, ensuring that the communication wiring, step pulse interfaces (STEP/DIR), limit switches, and other interfaces are mapped correctly
* **Steps per Degree Configuration**:
  * Core calculation formula: `(Physical motor steps per revolution × Microsteps × Total reduction ratio) / 360`
  * Using a standard 1.8° stepper motor (200 steps per revolution) and a size 25 harmonic reducer with a 1:100 ratio as an example, the exact value depends on the driver mode used

* **Mode A: TMC5160 SPI Intelligent Mode (Recommended 🚀)**:
  * **Driver Model**: Define the right ascension axis (RA) and declination axis (Dec) strictly as `TMC5160_SPI`
  * **Microstep Setting**: **64** or **128** is recommended. The TMC automatically interpolates to 256 microsteps internally for smoother sidereal tracking
  * **Parameter Example**: With 64 microsteps, the calculation is `(200 × 64 × 100) / 360 ≈ 3555.556`. Enter `3555.556` for `AXIS1_STEPS_PER_DEGREE` and `AXIS2_STEPS_PER_DEGREE`

* **Mode B: Traditional STEP/DIR Mode (Backward Compatible 🔌)**:
  * **Driver Model**: If SPI is disconnected with a jumper and an A4988, DRV8825, or standalone-mode TMC driver is used, change the driver model to the corresponding type, such as `A4988` or `GENERIC`
  * **Strict Microstep Matching**: ⚠️ `AXIS_MICROSTEPS` in the firmware **must exactly match** the physical microstep value set by the motherboard jumpers. In traditional STEP/DIR mode, the firmware cannot dynamically change the microstep setting
  * **Parameter Example**: If the physical jumpers are set to 32 microsteps, the calculation is `(200 × 32 × 100) / 360 ≈ 1777.778`. Enter this value for the corresponding steps parameter
  * **⚡ Current Setting (Manual Adjustment)**: In traditional mode, OnStep cannot control the current through software. With the motherboard powered on, use a multimeter to take measurements, and use a ceramic Phillips screwdriver to turn the potentiometer on the driver module extremely slowly to set the VREF reference voltage. **Be extremely careful during operation to avoid a short circuit!**

### 🚀 Flashing the Firmware and Uploading the Web UI

A complete OnStep installation on the ESP32 platform contains **two independent steps**: uploading the core firmware and uploading the file system. Both are required. The following procedure uses a TMC5160 driver as an example.

## Step 1: Upload the OnStep Core Firmware

1. Connect the controller board with a high-quality data cable. System communication relies on the onboard CP2102GMR chip, so make sure the official Silicon Labs driver is installed
2. Select the corresponding COM port in the IDE and click “Upload”
3. First disable SPI communication mode in `Config.h` to avoid errors caused by the shared I/O pins on this PCB and to prepare for flashing the ESP07S
   * *Note: If the terminal reports a `Connecting...` timeout, hold down the `BOOT` button on the PCB until the upload progress bar appears*

## Step 2: Upload the Smart Web Server

Controlling OnStep through Wi-Fi depends on web files stored in the ESP07S flash memory. Because the PCB has a compact design and does not provide a separate flashing channel for the ESP07S, the ESP32 must be used as a forwarding bridge to flash the ESP07S firmware.

* *Note: When flashing the ESP32, enable the `#define SERIAL_B_ESP_FLASHING` function in `Config.h` and use a jumper cap to connect the corresponding RST pins on the PCB*

---

## 📡 Guide to Flashing the ESP07S (SmartWebServer) Through ESP32 Passthrough

Strictly follow the sequence below. Any incorrect step may cause flashing to fail. If the reproduced structure is identical to this project, the relevant parameters can be copied directly.

**🛠️ Phase 1: Preparation**

To use a command-line tool for flashing, the source code cannot be uploaded directly, so a firmware file in `.bin` format must first be generated and the corresponding flashing tool must be prepared.

**1. Prepare the WiFi Firmware File (`.bin`)**

1. Open the ESP8266 WiFi (SmartWebServer) source code in the Arduino IDE
2. Select **`LOLIN (WeMos) D1 R2 & mini`** under **Tools -> Board**
3. Click the menu bar: **Sketch -> Export Compiled Binary**
4. Locate the newly generated `.bin` file in the source code folder and select the version with the shortest filename, such as `SmartWebServer.bin`
5. Copy the file to the root directory of the `D drive` and rename it to a simple filename, such as `wifi.bin`

**2. Prepare the Flashing Tool (`esptool`)**

Prepare `esptool.py` in a Python environment or the compiled standalone program `esptool.exe`.

* **If Python is already installed**: Open the CMD command prompt and enter `pip install esptool` to complete the installation
* **If Python is not installed**: Search for `esptool.exe` in the Arduino installation directory and copy it to the root directory of the `D drive` for later use

**🚀 Phase 2: Operating Procedure**

**Step 1: Establish the Passthrough Channel**

1. Connect the controller board containing the ESP32 to the computer through USB
2. Open the Arduino **Serial Monitor**
3. Enter `:ESPFLASH#` in the send box, then click send
4. **Critical Check**: At this point, OnStep automatically pulls IO26 (WiFi IO0) low according to the predefined pins, then pulls IO2 (WiFi RST) low and high. If this step succeeds, the ESP07S should have entered the “waiting for flashing” state
5. 🛑 **Close the Serial Monitor!** This step is extremely important. The COM port must be released for `esptool` in the next step

**Step 2: Execute the “No Reset” Flashing Command**

Open CMD (Command Prompt) on the computer and enter the following command according to the prepared tool. The example assumes that the file is located on the D drive and the port is `COM7`, so modify them according to the actual situation.

**Option A: Use `esptool.exe` (Windows Standalone Program)**

First enter `D:` and press Enter to switch to the D drive, then execute:

```bash
esptool.exe -p COM7 -b 115200 --before no_reset write_flash 0x00000 wifi.bin
```

**Option B: Use Python `esptool.py`**

Execute directly in CMD:

```bash
python -m esptool -p COM7 -b 115200 --before no_reset write_flash 0x00000 D:\wifi.bin
```

* *Note: The jumper cap can be removed after flashing is complete*

## Step 3: Re-upload the OnStep Core Firmware

1. Re-enable SPI communication mode in `Config.h` and disable `#define SERIAL_B_ESP_FLASHING`
2. Select the corresponding COM port in the IDE and click “Upload” to flash it again
3. After completing the steps above, flashing is complete and the system is ready for use

---

### 🔍 Detailed Parameter Description

* **`-p COM7`**: Specifies the port connected to the hardware
* **`-b 115200`**: **A low speed must be used!** Software passthrough cannot handle high baud rates such as 921600, and packet loss can easily occur when the controller forwards data through the software serial port
* **`--before no_reset`**: **Core parameter.** It tells the computer to “send data directly without attempting to restart the ESP32”, allowing the controller ESP32 to remain in passthrough mode and forward the data to the ESP07S
* *(If using PlatformIO, click the ant icon on the left and run the `Upload File System image` task.)*

> ⚠️
> **Initial Startup and Safety Verification:** After flashing is complete, the controller board creates a Wi-Fi hotspot named `OnStep` on its first startup (the default password is usually `password`). After connecting, enter `192.168.0.1` in the browser to access the control panel. **Strongly Recommended:** Before mounting an expensive telescope, perform a no-load test first and carefully verify the TMC5160 driver current setting, motor rotation direction, and limit switch trigger status to ensure that the high-torque harmonic reducer does not damage the mechanical structure

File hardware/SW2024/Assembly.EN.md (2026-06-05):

<div align="center">
  
  
</div>

# Dual 25-100 Harmonic Equatorial Mount Assembly Instructions

This manual, using real-life photos from the `pictures/Assembly process` directory, explains the complete assembly process step-by-step, from the mechanical structure to the electrical control system.

## 🛠️ Preparation and Bill of Materials (BOM)

Before starting assembly, please ensure you have the following core components and tools ready (refer to the BOM for specific hardware requirements):

* **Transmission Core**: 25-100 type harmonic reducer (1:100 reduction ratio)

* **Idler Gears**: 2GT 10mm wide 80-tooth idler gear and 2GT 10mm wide 19mm high 20-tooth idler gear

* **Motor and Protection**: Stepper motor, power-off brake (electromagnetic damping/holding brake) module

* **Main Control and Drive**: ESP32 + ESP07S combination, TMC5160 stepper motor drive module

* **Circuit Board**: Custom-designed main control PCB (supports 12V/24V) Power plane)

* **Wires and accessories**: **Power switch lead wire**, various types of hex socket screws, lubricant, screw glue

*Note: For the idler gear, you need to have certain machining capabilities to modify the finished idler gear according to the specifications in the drawing. If you cannot modify it, please modify the model yourself to adapt to standard parts on the market.*

---

## ⚙️ Stage 1: Mechanical Structure Assembly

### 1. Installation of Harmonic Reducer (RA/DEC Axis)
In this step, we will install the core component of the equatorial mount. Considering the stress requirements of the radial slow rotation load, please ensure that the flange contact surface is flat and fits snugly during installation.

1. Accurately align the reducer flange face with the screw holes of the aluminum plate, and try to make the center round hole of the aluminum plate coaxial with the hollow shaft of the reducer. Use hex socket screws and tighten them evenly in a diagonal sequence to ensure that the reducer housing is subjected to uniform force and avoid deformation caused by excessive tightness or vibration caused by excessive looseness.

2. Two of the screw holes require longer screws and do not need to be fitted with lock nuts for subsequent motor mount installation.

3. Four of the screw holes do not require screws for subsequent installation of the 3D-printed reducer protective cover.

4. Tighten the excess parts of the remaining core screw assembly (excluding those from step 2) into lock nuts to ensure a secure connection between the reducer and the aluminum plate that will not loosen due to vibration.

> 📷 *Reference Image:*

> Installing Harmonic Reducer

> Installing Harmonic Reducer "Installing the Harmonic Reducer")

> Installing the Harmonic Reducer

### 2. Assembly of the Transmission Part

1. Install the machined 80-gear 2GT idler wheel on the input shaft of the reducer, ensuring that the idler wheel is coaxial with the input shaft. Use hex socket screws and tighten them evenly in a diagonal sequence to ensure a firm connection that will not loosen due to vibration.

2. Install the 20-gear 2GT idler wheel on the output shaft of the stepper motor.

3. Install the stepper motor onto the motor mount using copper pillars.

4. **Power-off Brake Installation**: Replace the original motor screws at the tail end of the dual-output stepper motor used for the RA axis and install an electromagnetic brake module. This effectively prevents damage to the telescope's "head" due to the unbalanced weight when the equipment is unexpectedly powered off.

5. Beforehand, slip a 2GT 10mm wide synchronous belt onto the motor idler pulley to facilitate subsequent installation.

> 📷 *Reference Image:*

> RA Axis Motor and Brake Module Installation

> RA Axis Motor and Brake Module Installation DEC Axis Motor Installation

### 3. Assembly of RA Axis Latitude Seat Flange

1. Connect the RA axis flange to connecting shaft A and connecting shaft B using hex socket head cap screws.

2. During step 1, simultaneously assemble the push rod and push block structure, ensuring the push rod can slide smoothly within the push block, and that connecting shaft A and connecting shaft B can achieve relative movement through the push rod.

3. Install the assembled structure from steps 1 and 2 onto the flange of the harmonic reducer using hex socket head cap screws. Simultaneously install the 3D-printed reducer protective cover during the installation process.

> 📷 *Reference Image:*

> Assembly of Latitude Constellation

> Assembly of Latitude Constellation

> Assembly of Latitude Constellation

### 4. Connection of motor, synchronous belt, and reducer, as well as installation of sensors and flanges:

1. Install the synchronous belt onto the pre-drilled holes on the motor mount using the longer screws pre-drilled on the aluminum plate in step 1. Tighten the synchronous belt and tighten the lock nuts on the screws to ensure that the synchronous belt does not slip or become excessively loose during transmission.

2. Adjust the height of the idler pulley on the motor output shaft appropriately so that it is level with the idler pulley on the reducer input shaft. This ensures even tension distribution of the synchronous belt and avoids excessive wear or reduced transmission efficiency due to non-parallelism.

3. After completing the above steps, manually rotate the large idler pulley to check if the synchronous belt runs smoothly and ensure there are no abnormal friction sounds or vibrations. This will help confirm the correct installation and adjustment of the transmission system.

4. After installation, it is recommended to spray an appropriate amount of silicone lubricant on the synchronous belt to reduce friction and abnormal noise and extend the service life of the synchronous belt.

5. Install the photoelectric sensor limit switches and origin switches on the RA/DEC shaft, ensuring that their positions can accurately detect the extreme and origin positions of the shaft for safety protection and precise positioning.

6. Install the 3D-printed reducer protective cover on the outside of the reducer, and fix it with the reserved screw holes and hex screws to ensure that the protective cover can effectively prevent dust and debris from entering the reducer, while not interfering with its normal operation. 7. Install the flange of the RA/DEC shaft, ensuring that it is coaxial with the shaft, and tighten it evenly with hex screws to ensure that the flange will not shift or loosen during operation. 📷 *Reference image:* Installation of RA shaft motor and brake module, sensor, flange DEC Axis Motor, Synchronous Belt, and Sensor Installation

> DEC Axis Flange Installation

### 5. Housing Assembly

1. Connect the assembled RA and DEC axes mechanical structures using aluminum blocks, ensuring all aluminum plates are vertically and orthogonally installed without interference using a marble horizontal surface.

2. Apply an appropriate amount of threadlocker to the screw connections to ensure the stability and reliability of the mechanical connections during equipment operation.

> 📷 *Reference Image:*

> Shell Assembly

---

## ⚡ Phase Two: Electrical Control Assembly and Wiring

### 1. PCB Baseboard and Driver Installation

1. Fix the completed PCB board inside the electrical control compartment using copper pillars. During installation, carefully check the 12V/24V high-current power supply plane on the back to ensure sufficient insulation distance between it and the metal casing.

2. Connect the TMC5160 driver module and ESP32 main control board to the corresponding female connectors in sequence. Pay attention to the pin orientation and do not reverse them.

> 📷 *Reference Images:*

> PCB and Driver Installation

> PCB and Driver Installation

### 2. Standard Wiring and Cable Management To ensure the absolute stability of the equipment in outdoor environments and under high current driving conditions, the wiring in this project has strict requirements:

1. The main power supply line must use standard **power switch leads** to connect to the PCB. **The use of any arbitrary "flying wires"** as a substitute for the power path is strictly prohibited.

2. Connect the control wires of the RA and DEC axis stepper motors to the corresponding terminals on the TMC5160.

3. Connect the control wires of the power-off protection system and tidy up all wiring harnesses to ensure that the cables do not become tangled or excessively stretched during the extreme rotation of the equatorial mount.

> 📷 *Reference Image:*

> Standard Power Leads and Internal Routing

---

## 💻 Phase Three: Firmware Configuration and Initial Debugging

The hardware logic of the Dual 25 is designed for a standard OnStep environment.

1. **Firmware Selection:** The system runs **standard OnStep firmware** (⚠️Please note: OnStepX is **not applicable to this project; do not flash the wrong firmware version**).

2. **Communication Confirmation:** Ensure the ESP32 pin mapping matches your modified OnStep firmware, and confirm the ESP07S's network communication connection is normal.

3. **Power-On Self-Test:** Connect to power and test whether the electromagnetic brake can engage/release normally. Monitor the TMC5160's operating status and microstepping settings via the host computer.

> 📷 *Reference Image:*

> Electronic Control System Illumination and Online Testing Electronic Control System Lighting and Online Testing

> Electronic Control System Lighting and Online Testing

---

## 🤝 Open Source License and Contributions

If you find any optimizable mechanical tolerances or better wiring solutions during the assembly process, please submit an Issue or Pull Request. This project uses the `GPLv3 + CERN-OHL-S` dual open source license. Thank you for your contribution to the open source astronomical hardware community!







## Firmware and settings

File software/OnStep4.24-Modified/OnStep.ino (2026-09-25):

/*
 * 标题          OnStep
 * 作者          Howard Dutton
 *
 * 版权所有 (C) 2012 至 2021 Howard Dutton
 *
 * 本程序为自由软件：您可以根据自由软件基金会发布的 GNU 通用公共许可证（GNU GPL）
 * 的条款重新分发和/或修改它，无论是许可证的第 3 版，还是（由您选择）任何更高版本
 *
 * 本程序的发布是希望它能有用，但【没有任何担保】；
 * 甚至没有对【适销性】或【特定用途适用性】的暗示性担保
 * 有关更多详细信息，请参阅 GNU 通用公共许可证
 *
 * 您应该随本程序一起收到了一份 GNU 通用公共许可证的副本
 * 如果没有，请参阅 <http://www.gnu.org/licenses/>
 *
 * 描述:
 * 功能齐全的步进电机望远镜微控制器，适用于赤道仪和经纬仪支架，
 * 采用衍生自 LX200 的指令集
 *
 * 作者: Howard Dutton
 * http://www.stellarjourney.com
 * hjd1964@gmail.com
 *
 * 修订历史和更新版本:
 * 请参阅 GitHub: https://github.com/hjd1964/OnStep
 *
 * 文档:
 * https://groups.io/g/onstep/wiki/home
 *
 * 讨论、提问等:
 * https://groups.io/g/onstep
 */

// 请使用 Config.h 文件根据您的需求来配置 OnStep
// 固件信息，这些信息由 ":GV?#" 命令返回

#define FirmwareDate          __DATE__
#define FirmwareVersionMajor  4
#define FirmwareVersionMinor  24      // 次版本号 0 到 99
#define FirmwareVersionPatch  "s"     // 补丁版本，例如主.次 补丁: 1.3c
#define FirmwareVersionConfig 3       // 内部使用，用于跟踪配置文件更改
#define FirmwareName          "On-Step"
#define FirmwareTime          __TIME__

#include "Constants.h"

// --- 限位锁死状态变量 ---
// 0=无锁死, 1=正向锁死(如East/North), -1=反向锁死(如West/South)
int Axis1_LimitLock = 0;
int Axis2_LimitLock = 0;
unsigned long lastLimitTriggerTime = 0; // 用于非阻塞消抖计时
// GOTO 安全中断分类该状态与 HOME_SENSE / LIMIT_SENSE 的编译配置无关
// 避免关闭传感器后安全中断被误判为正常 GOTO 完成
enum GotoAbortState { GOTO_ABORT_NONE, GOTO_ABORT_STOPPED, GOTO_ABORT_HARD_STOP, GOTO_ABORT_POSITION_LOST };
GotoAbortState gotoAbortState = GOTO_ABORT_NONE;

// Only a normal celestial GOTO may request sidereal tracking on successful arrival.
bool gotoStartTrackingOnSuccess = false;

// 当前步数坐标是否仍可作为真实机械位置使用
// 标准 OnStep 启动假定赤道仪位于已知起始位置；HOME_REQUIRED_ON_BOOT 可要求先回零确认
bool mountPositionTrusted = true;

// 物理限位、驱动器故障或失败的传感器回零会置位
// HOME_SENSE 开启时可通过自动回零恢复；HOME_SENSE 关闭时可在人工放回零位后执行 Set Home 恢复
bool positionRecoveryRequired = false;

// 首次上传时，OnStep 会自动初始化 nv 存储器（EEPROM）中的一系列设置
// 此选项会强制再次进行初始化
// 将其改为 ON，上传 OnStep，nv 将被重置为默认值
// 等待约 30 秒后，将其设置为 OFF 并再次上传
// *** 重要提示：此选项不得一直设置为 true (ON)，否则会导致 EEPROM 或 FLASH 过度损耗 ***
#define NV_FACTORY_RESET OFF

// 在指定的 DebugSer 端口上启用额外的调试和/或状态消息
// 请注意，DebugSer 端口不能用于与 OnStep 的正常通信（如控制望远镜）
#define DEBUG OFF             // 默认=OFF使用 "DEBUG ON" 仅显示后台错误，
                              // 使用 "DEBUG VERBOSE" 显示所有错误和状态消息
#define DebugSer SerialA      // 默认=SerialA，或者例如 Serial4（始终为 9600 波特率）

#include <errno.h>
#include <math.h>

#include "src/sd_drivers/Models.h"
#include "Config.h"
#include "src/pinmaps/Models.h"
#include "src/HAL/HAL.h"
#include "Validate.h"

// 用于调试的辅助宏，减少打字量
#if DEBUG != OFF
  #define D(x)       DebugSer.print(x)
  #define DF(x)      DebugSer.print(F(x))
  #define DL(x)      DebugSer.println(x)
  #define DLF(x)     DebugSer.println(F(x))
#else
  #define D(x)
  #define DF(x)
  #define DL(x)
  #define DLF(x)
#endif
#if DEBUG == VERBOSE
  #define V(x)        DebugSer.print(x)
  #define VF(x)       DebugSer.print(F(x))
  #define VL(x)       DebugSer.println(x)
  #define VLF(x)      DebugSer.println(F(x))
#else
  #define V(x)
  #define VF(x)
  #define VL(x)
  #define VLF(x)
#endif
// ---------------------------------------------------------------------------------------------------

#include "src/lib/St4SerialMaster.h"
#include "src/lib/FPoint.h"
#include "src/lib/Heater.h"
#include "src/lib/Intervalometer.h"
#include "Globals.h"
#include "src/lib/Julian.h"
#include "src/lib/Misc.h"
#include "src/lib/Sound.h"
#include "src/lib/Coord.h"
#include "Align.h"
#include "src/lib/Library.h"
#include "src/lib/Command.h"
#include "src/lib/TLS.h"
#include "src/lib/Weather.h"
weather ambient;
#if SERIAL_B_ESP_FLASHING == ON || defined(AddonTriggerPin)
  #include "src/lib/flashAddon.h"
  flashAddon fa;
#endif

#if ROTATOR == ON
  #include "src/lib/Rotator.h"
  rotator rot;
#endif

#if FOCUSER1 == ON || FOCUSER2 == ON
  #include "src/lib/Focuser.h"
  #if FOCUSER1 == ON
    #if AXIS4_DRIVER_DC_MODE != OFF
      #include "src/lib/FocuserDC.h"
      focuserDC foc1;
    #else
      #include "src/lib/FocuserStepper.h"
      focuserStepper foc1;
    #endif
  #endif
  #if FOCUSER2 == ON
    #if AXIS5_DRIVER_DC_MODE != OFF
      #include "src/lib/FocuserDC.h"
      focuserDC foc2;
    #else
      #include "src/lib/FocuserStepper.h"
      focuserStepper foc2;
    #endif
  #endif
#endif

// 支持 SPI 模式下的 TMC2130、TMC5160 等步进电机驱动器
#if (AXIS1_DRIVER_MODEL == TMC_SPI && AXIS2_DRIVER_MODEL == TMC_SPI) || \
    (ROTATOR == ON && AXIS3_DRIVER_MODEL == TMC_SPI) || \
    (FOCUSER1 == ON && AXIS4_DRIVER_MODEL == TMC_SPI) || \
    (FOCUSER2 == ON && AXIS5_DRIVER_MODEL == TMC_SPI)
  #include "src/lib/SoftSPI.h"
  #include "src/lib/TMC_SPI.h"
  #if AXIS1_DRIVER_MODEL == TMC_SPI
    tmcSpiDriver tmcAxis1(Axis1_M2,Axis1_M1,(AXIS1_DRIVER_STATUS == TMC_SPI)?Axis1_M3:-1,Axis1_M0,AXIS1_DRIVER_SUBMODEL,AXIS1_DRIVER_RSENSE);
  #endif
  #if AXIS2_DRIVER_MODEL == TMC_SPI
    tmcSpiDriver tmcAxis2(Axis2_M2,Axis2_M1,(AXIS2_DRIVER_STATUS == TMC_SPI)?Axis2_M3:-1,Axis2_M0,AXIS2_DRIVER_SUBMODEL,AXIS2_DRIVER_RSENSE);
  #endif
  #if AXIS3_DRIVER_MODEL == TMC_SPI
    tmcSpiDriver tmcAxis3(Axis3_M2,Axis3_M1,-1,Axis3_M0,AXIS3_DRIVER_SUBMODEL,AXIS3_DRIVER_RSENSE);
  #endif
  #if AXIS4_DRIVER_MODEL == TMC_SPI
    tmcSpiDriver tmcAxis4(Axis4_M2,Axis4_M1,-1,Axis4_M0,AXIS4_DRIVER_SUBMODEL,AXIS4_DRIVER_RSENSE);
  #endif
  #if AXIS5_DRIVER_MODEL == TMC_SPI
    tmcSpiDriver tmcAxis5(Axis5_M2,Axis5_M1,-1,Axis5_M0,AXIS5_DRIVER_SUBMODEL,AXIS5_DRIVER_RSENSE);
  #endif
#endif

// 恢复状态与原版运动状态解耦：可信且无需恢复=正常；可信但需恢复=仅允许坐标回零；
// 不可信且需恢复=必须通过传感器 Home 或 Set Home 重建位置基准
void clearPhysicalLimitState() {
  Axis1_LimitLock = 0;
  Axis2_LimitLock = 0;
}

bool positionReady() {
  return mountPositionTrusted && !positionRecoveryRequired;
}

bool positionHomeReturnOnly() {
  return mountPositionTrusted && positionRecoveryRequired;
}

void requireCoordinateHomeRecovery() {
  mountPositionTrusted = true;
  positionRecoveryRequired = true;
  gotoStartTrackingOnSuccess = false;
}

void invalidatePositionReference() {
  mountPositionTrusted = false;
  positionRecoveryRequired = true;
  gotoStartTrackingOnSuccess = false;
}

void completePositionRecovery() {
  mountPositionTrusted = true;
  positionRecoveryRequired = false;
  gotoAbortState = GOTO_ABORT_NONE;
  gotoStartTrackingOnSuccess = false;
  clearPhysicalLimitState();
}

void setup() {
  initPre();
  // 初始化 ESP8266 插件（Addon）烧录器
#if SERIAL_B_ESP_FLASHING == ON
  fa.init(-1,AddonResetPin,AddonBootModePin);
#elif defined(AddonTriggerPin)
  fa.init(AddonTriggerPin,AddonResetPin,AddonBootModePin);
#endif

  // 等待半秒钟，让所有连接的设备启动完毕，然后再开始设置引脚
  delay(10);//[修改] 缩短等待时间，原始值500
#if DEBUG != OFF
  // 提前初始化 USB 串口调试，以便在需要时可以使用 DebugSer.print() 进行调试
  DebugSer.begin(9600);
  delay(5000); DebugSer.flush(); VLF(""); VLF("");
#endif

  // 打印欢迎信息/版本号
  VF("MSG: OnStep "); V(FirmwareVersionMajor); V("."); V(FirmwareVersionMinor); VL(FirmwareVersionPatch);
  VF("MSG: MCU =  "); VF(MCU_STR); V(", "); VF("Pinmap = "); VLF(PINMAP_STR);
  // 调用硬件特定初始化
  VLF("MSG: Init HAL");
  HAL_Initialize();

  VLF("MSG: Init serial");
  // 等待半秒钟，让串口缓冲区清空，然后再可能需要重启调试端口
  delay(10);// [修改2] 缩短串口缓冲等待，原始值500
  SerialA.begin(SERIAL_A_BAUD_DEFAULT);
#ifdef HAL_SERIAL_B_ENABLED
  #ifdef SERIAL_B_RX
    SerialB.begin(SERIAL_B_BAUD_DEFAULT, SERIAL_8N1, SERIAL_B_RX, SERIAL_B_TX);
  #else
    SerialB.begin(SERIAL_B_BAUD_DEFAULT);
  #endif
#endif
#ifdef HAL_SERIAL_C_ENABLED
  SerialC.begin(SERIAL_C_BAUD_DEFAULT);
#endif
#ifdef HAL_SERIAL_D_ENABLED
  #ifdef SERIAL_D_RX
    SerialD.begin(SERIAL_D_BAUD_DEFAULT, SERIAL_8N1, SERIAL_D_RX, SERIAL_D_TX);
  #else
    SerialD.begin(SERIAL_D_BAUD_DEFAULT);
  #endif
#endif
#ifdef HAL_SERIAL_E_ENABLED
  SerialE.begin(SERIAL_E_BAUD_DEFAULT);
#endif
#if TIME_LOCATION_SOURCE == GPS
  #ifdef SERIAL_GPS_RX
    SerialGPS.begin(SERIAL_GPS_BAUD, SERIAL_8N1, SERIAL_GPS_RX, SERIAL_GPS_TX);
  #else
    SerialGPS.begin(SERIAL_GPS_BAUD);
  #endif
#endif
#if ST4_HAND_CONTROL == ON && ST4_INTERFACE != OFF
  SerialST4.begin();
#endif

  // 再等待两秒钟，以确保串口完全上线
  delay(100);// [修改3] 缩短串口上线等待 (从2000改到100，兼容SPI初始化时间)，原始值2000
  // 根据 Config.h 和 PinMap.h 中的定义设置输入/输出引脚
  VLF("MSG: Init pins");
  initPins();

  // 准备好 TLS（时间地点源）（如果存在）
  VLF("MSG: Init TLS");
  if (!tls.init()) generalError=ERR_SITE_INIT;
  // 检查非易失性存储器 (NV Memory)
  VF("MSG: Start NV ");
  if (!nv.init()) {
    VLF("");
    SerialA.print("NV (EEPROM) failure!#\r\n");
    while (true) {
      delay(10);
      #ifdef HAL_SERIAL_TRANSMIT
        SerialA.transmit();
      #endif
    }
  }
  V(E2END+1);
  VLF(" Bytes");

  // 如果是首次启动，则将 EEPROM 设置为默认值
  initWriteNvValues();
  // 现在从 EEPROM 中读取已保存的值到变量中，以恢复我们之前的状态
  VLF("MSG: Read NV settings");
  initReadNvValues();

  // 设置某些变量的初始值
  VLF("MSG: Init startup settings");
  initStartupValues();
  initStartPosition();
  // 初始化天体对象库 (Object Library)
  VLF("MSG: Init library/catalogs");
  Lib.init();
  // 准备好导星功能
  VLF("MSG: Init guiding");
  initGuide();
  // 准备好天气监测设备
#ifdef ONEWIRE_DEVICES_PRESENT
  VLF("MSG: Init weather and 1-Wire");
#else
  VLF("MSG: Init weather");
#endif
  if (!ambient.init() && WEATHER_SUPRESS_ERRORS == OFF) generalError=ERR_WEATHER_INIT;
  // 设置辅助功能
#ifdef FEATURES_PRESENT
  VLF("MSG: Init auxiliary features");
  featuresInit();
#endif

  // 这会设置恒星时计时器和跟踪速率
  VLF("MSG: Init sidereal timer");
  siderealInterval=nv.readLong(EE_siderealInterval); // 一个恒星秒内的 16MHz 时钟数（这是根据实际处理器速度缩放的）
  if (siderealInterval < 14360682L || siderealInterval > 17551944L) { DF("ERR, setup(): bad NV siderealInterval ("); D(siderealInterval); DL(")");
  siderealInterval=masterSiderealInterval; }
  siderealRate=siderealInterval/stepsPerSecondAxis1;
  timerRateAxis1=siderealRate;
  timerRateAxis2=siderealRate;

  // 设置反向间隙补偿（Backlash）速率
  backlashTakeupRate=siderealRate/TRACK_BACKLASH_RATE;
  timerRateBacklashAxis1=siderealRate/TRACK_BACKLASH_RATE;
  timerRateBacklashAxis2=(siderealRate/TRACK_BACKLASH_RATE)*timerRateRatio;
  // 设置步进电机驱动模式
  VLF("MSG: Init motor timers");
  StepperModeTrackingInit();
  // 启动保持恒星时、驱动电机等的硬件定时器
  setTrackingRate(DefaultTrackingRate);
  setDeltaTrackingRate();
  initStartTimers();
  // 跟踪自动启动逻辑
// 跟踪自动启动逻辑：只负责真正的 tracking autostart
#if TRACK_AUTOSTART == ON
  #if MOUNT_TYPE != ALTAZM

    if (!tls.active) {
      VLF("MSG: Tracking autostart - TLS/orientation unknown, limits disabled");
      setHome();
      safetyLimitsOn = false;
    } else {
      if (parkStatus != Parked) {
        VLF("MSG: Tracking autostart - TLS/orientation unknown, limits disabled");
        setHome();
        safetyLimitsOn = false;
      } else {
        VLF("MSG: Tracking autostart - assuming TLS/orientation are correct, limits enabled and automatic unpark");
        unPark(true);
      }
    }

    trackingState = TrackingSidereal;
    enableStepperDrivers();

  #else
    #warning "Tracking autostart ignored for MOUNT_TYPE ALTAZM"
  #endif

#else
  if (parkStatus == Parked) {
    VLF("MSG: Restoring parked telescope pointing state");
    unPark(false);
  }
#endif


// 独立的开机回零策略
#if HOME_REQUIRED_ON_BOOT == ON
  #if MOUNT_TYPE != ALTAZM
    VLF("MSG: Home/Set Home required before GOTO/tracking");
    #if HOME_SENSE == OFF
      // 启动步数仍描述 Home，但客户端必须显式执行/确认回零
      requireCoordinateHomeRecovery();
    #else
      invalidatePositionReference();
    #endif
    gotoAbortState = GOTO_ABORT_NONE;
    trackingState = TrackingNone;
    lastTrackingState = TrackingNone;
    abortTrackingState = TrackingNone;
    safetyLimitsOn = false;
  #endif
#endif

#if MOTOR_HOLD_ON_BOOT == ON
  #if MOUNT_TYPE != ALTAZM

    VLF("MSG: Motor hold on boot - drivers enabled");

    // 电机使能，但不发跟踪脉冲
    enableStepperDrivers();

    // 使用 tracking 微步/电流保持
    axis1DriverTrackingMode(false);
    axis2DriverTrackingMode(false);

  #endif
#endif

  // 如果存在，则启动旋转器 (Rotator)
#if ROTATOR == ON
  VLF("MSG: Init rotator");
  rot.init(Axis3_STEP,Axis3_DIR,Axis3_EN,EE_rotBaseAxis3,AXIS3_STEP_RATE_MAX,axis3Settings.stepsPerMeasure,axis3Settings.min,axis3Settings.max);
  if (axis3Settings.reverse == ON) rot.setReverseState(HIGH);
  rot.setDisableState(AXIS3_DRIVER_DISABLE);
  
  #if AXIS3_DRIVER_MODEL == TMC_SPI
    tmcAxis3.setup(AXIS3_DRIVER_INTPOL,AXIS3_DRIVER_DECAY_MODE,AXIS3_DRIVER_CODE,axis3Settings.IRUN,axis3Settings.IRUN);
    delay(150);
    tmcAxis3.setup(AXIS3_DRIVER_INTPOL,AXIS3_DRIVER_DECAY_MODE,AXIS3_DRIVER_CODE,axis3Settings.IRUN,axis3SettingsEx.IHOLD);
  #endif
  
  rot.powerDownActive(AXIS3_DRIVER_POWER_DOWN == ON);
#endif

  // 如果存在，则启动调焦器 (Focusers)
#if FOCUSER1 == ON
  VLF("MSG: Init focuser1");
  foc1.init(Axis4_STEP,Axis4_DIR,Axis4_EN,EE_focBaseAxis4,AXIS4_STEP_RATE_MAX,axis4Settings.stepsPerMeasure,axis4Settings.min*1000.0,axis4Settings.max*1000.0,AXIS4_LIMIT_MIN_RATE);
  if (AXIS4_DRIVER_DC_MODE != OFF) foc1.setPhase1();
  if (axis4Settings.reverse == ON) foc1.setReverseState(HIGH);
  foc1.setDisableState(AXIS4_DRIVER_DISABLE);

  #if AXIS4_DRIVER_MODEL == TMC_SPI
    tmcAxis4.setup(AXIS4_DRIVER_INTPOL,AXIS4_DRIVER_DECAY_MODE,AXIS4_DRIVER_CODE,axis4Settings.IRUN,axis4Settings.IRUN);
    delay(150);
    tmcAxis4.setup(AXIS4_DRIVER_INTPOL,AXIS4_DRIVER_DECAY_MODE,AXIS4_DRIVER_CODE,axis4Settings.IRUN,axis4SettingsEx.IHOLD);
  #endif

  foc1.powerDownActive(AXIS4_DRIVER_POWER_DOWN == ON, AXIS4_DRIVER_POWER_DOWN == STARTUP);
#endif

#if FOCUSER2 == ON
  VLF("MSG: Init focuser2");
  foc2.init(Axis5_STEP,Axis5_DIR,Axis5_EN,EE_focBaseAxis5,AXIS5_STEP_RATE_MAX,axis5Settings.stepsPerMeasure,axis5Settings.min*1000.0,axis5Settings.max*1000.0,AXIS5_LIMIT_MIN_RATE);
  if (AXIS5_DRIVER_DC_MODE != OFF) foc2.setPhase2();
  if (axis5Settings.reverse == ON) foc2.setReverseState(HIGH);
  foc2.setDisableState(AXIS5_DRIVER_DISABLE);

  #if AXIS5_DRIVER_MODEL == TMC_SPI
    tmcAxis5.setup(AXIS5_DRIVER_INTPOL,AXIS5_DRIVER_DECAY_MODE,AXIS5_DRIVER_CODE,axis5Settings.IRUN,axis5Settings.IRUN);
    delay(150);
    tmcAxis5.setup(AXIS5_DRIVER_INTPOL,AXIS5_DRIVER_DECAY_MODE,AXIS5_DRIVER_CODE,axis5Settings.IRUN,axis5SettingsEx.IHOLD);
  #endif

  foc2.powerDownActive(AXIS5_DRIVER_POWER_DOWN == ON, AXIS5_DRIVER_POWER_DOWN == STARTUP);
#endif

  // 最后清除通信通道
  VLF("MSG: Serial buffer flush");
  delay(10);// [修改4] 缩短最后的缓冲清除等待，原始值500
  SerialA.flush();
  while (SerialA.available()) SerialA.read();
#ifdef HAL_SERIAL_B_ENABLED
  SerialB.flush();
  while (SerialB.available()) SerialB.read();
#endif
#ifdef HAL_SERIAL_C_ENABLED
  SerialC.flush();
  while (SerialC.available()) SerialC.read();
#endif
#ifdef HAL_SERIAL_D_ENABLED
  SerialD.flush();
  while (SerialD.available()) SerialD.read();
#endif
#ifdef HAL_SERIAL_E_ENABLED
  SerialE.flush();
  while (SerialE.available()) SerialE.read();
#endif
  delay(500);
  // 准备计数器（用于在主循环中计时）
  cli(); siderealTimer=lst; guideSiderealTimer=lst; pecSiderealTimer=lst; sei();
  last_loop_micros=micros();
  VLF("MSG: OnStep is ready"); VL("");
}

void loop() {
  loop2();
  Align.model(0);
  // GTA 计算指向模型，这将在扩展处理期间调用 loop2()
}

void loop2() {
  // 每轮先接收命令，避免周期任务持续到期时停止指令得不到处理
  processCommands();

#if HOME_SENSE != OFF
  // 监听自动回原点 (Homing) 状态
  static bool wasHoming = false;
  if (isHoming()) {
      wasHoming = true; // 系统正在回原点
  } else if (wasHoming) {
      // 不在主循环里直接把 mountPositionTrusted 置 true
      // 真实自动回零成功只由 Home.ino 的 FH_DONE 阶段确认，避免回零失败也误解锁
      wasHoming = false;
  }
#endif

  // 导星 (GUIDING) 
  ST4();
  if ((trackingState != TrackingMoveTo) && (parkStatus == NotParked)) guide();

#if HOME_SENSE != OFF
  // 自动回原点 (AUTOMATIC HOMING) 
  checkHome();
#endif

  // 1/100 秒定时任务 
  cli(); long lstNow=lst; sei();
  if (lstNow != siderealTimer) {
    siderealTimer=lstNow;

#ifdef ESP32
    timerSupervisor(true);
#endif
    
#if AXIS1_PEC == ON
    // 周期误差修正 (PEC)
    pec();
#endif

    // 恒星跟踪期间闪烁 LED
#if LED_STATUS == ON
    if (trackingState == TrackingSidereal) {
      if (siderealTimer%20L == 0L) { if (ledOn) { digitalWrite(LEDnegPin,HIGH);
      ledOn=false; } else { digitalWrite(LEDnegPin,LOW); ledOn=true; } }
    }
#endif

    // GOTO 期间保持恒星跟踪计算
    // 确保 GOTO 过程中目标位置依然随时间更新
    if (trackingState == TrackingMoveTo) {
      moveTo();
      //一个正常的天空Goto从发动机保持仍然必须遵循
      //恒星目标在移动时保持上次跟踪状态不变
      //因此，中止的Goto会恢复到Goto之前的真实状态（TrackingNone）
      if (lastTrackingState == TrackingSidereal || gotoStartTrackingOnSuccess) {
        origTargetAxis1.fixed+=fstepAxis1.fixed;
        origTargetAxis2.fixed+=fstepAxis2.fixed;
        // 中天翻转分阶段交接期间不推进无效的中间目标
        if (getInstrPierSide() == PierSideEast || getInstrPierSide() == PierSideWest) {
          cli();
          targetAxis1.fixed+=fstepAxis1.fixed;
          targetAxis2.fixed+=fstepAxis2.fixed;
          sei();
        }
      }
    }

    // 旋转器/调焦器，移动目标
#if ROTATOR == ON
    rot.poll(trackingState == TrackingSidereal);
#endif
#if FOCUSER1 == ON
    foc1.poll();
#endif
#if FOCUSER2 == ON
    foc2.poll();
#endif

    // 计算一些跟踪速率等
    if (lstNow%3 == 0) doFastAltCalc(false);
#if MOUNT_TYPE == ALTAZM
    // 计算当前的 Alt/Azm（经纬仪）跟踪速率
    if (lstNow%3 != 0) doHorRateCalc();
#else
    // 计算当前大气折射补偿后的跟踪速率
    if (rateCompensation != RC_NONE && lstNow%3 != 0) doRefractionRateCalc();
#endif

#if LIMIT_SENSE != OFF
    byte limit_reading = digitalRead(LimitPin);
    unsigned long currentTime = millis(); 
    
    // [检测到限位触发]
    if (limit_reading == LIMIT_SENSE_STATE) {
      
      lastLimitTriggerTime = currentTime;
      // 回零期间只跳过限位制动，继续执行主循环中的其余任务
      const bool homing = isHoming();
      if (homing) {
        Axis1_LimitLock=0;
        Axis2_LimitLock=0;
      }
        // =========================================================
        // 1. 物理限位触发，立即停止所有运动
        // =========================================================
      if (!homing) delay(2);
      if (!homing && digitalRead(LimitPin) == LIMIT_SENSE_STATE) {
        // =========================================================
        // 2. 统一方向定义
        // =========================================================
        int currentMotionDir1 = 0;
        int currentMotionDir2 = 0;

        // --- Axis 1 (RA) ---
        if (guideDirAxis1 == 'e') currentMotionDir1 = 1;       
        else if (guideDirAxis1 == 'w') currentMotionDir1 = -1; 
        else if (trackingState == TrackingMoveTo) {            
             if (targetAxis1.part.m < posAxis1) currentMotionDir1 = 1; 
             else if (targetAxis1.part.m > posAxis1) currentMotionDir1 = -1; 
        }

        // --- Axis 2 (DEC) ---
        if (guideDirAxis2 == 'n') currentMotionDir2 = 1;       
        else if (guideDirAxis2 == 's') currentMotionDir2 = -1; 
        else if (trackingState == TrackingMoveTo) {            
             if (targetAxis2.part.m > posAxis2) currentMotionDir2 = 1; 
             else if (targetAxis2.part.m < posAxis2) currentMotionDir2 = -1; 
        }

        // =========================================================
        // 3. 记录触发方向并保留静止状态兜底判断
        // =========================================================
        
        // --- Axis 1 智能判断 ---
        if (Axis1_LimitLock == 0) {
            // 手动控制和 GOTO 都优先记录限位触发瞬间的运动方向
            if (currentMotionDir1 != 0) {
                Axis1_LimitLock = currentMotionDir1;
            } else {
                // 静止状态下触发时才通过绝对坐标推断限位方向
                long threshold = 500L; // 容错阈值
                if (posAxis1 > threshold) Axis1_LimitLock = -1;       // 在西半区，锁西 (-1)
                else if (posAxis1 < -threshold) Axis1_LimitLock = 1;  // 在东半区，锁东 (1)
                else if (currentMotionDir1 != 0) Axis1_LimitLock = currentMotionDir1; // 兜底
            }
        }

        // --- Axis 2 智能判断 ---
        if (Axis2_LimitLock == 0) {
            // 手动控制和 GOTO 都优先记录限位触发瞬间的运动方向
            if (currentMotionDir2 != 0) {
                Axis2_LimitLock = currentMotionDir2;
            } else {
                long threshold = 500L;
                if (posAxis2 > threshold) Axis2_LimitLock = 1;        // 在北半区，锁北 (1)
                else if (posAxis2 < -threshold) Axis2_LimitLock = -1; // 在南半区，锁南 (-1)
                else if (currentMotionDir2 != 0) Axis2_LimitLock = currentMotionDir2;
            }
        }

        // =========================================================
        // 4. 逃离判断 (Escape Logic)
        // =========================================================
        // 只有所有正在移动且已锁定的轴都朝脱离限位方向运动时，
        // 才允许继续旧逻辑使用 OR，可能出现一个轴在逃离、另一个轴仍
        // 朝限位方向运动却被整体判定为安全
        const bool axis1MovingIntoLimit =
          Axis1_LimitLock != 0 && currentMotionDir1 != 0 && currentMotionDir1 == Axis1_LimitLock;
        const bool axis2MovingIntoLimit =
          Axis2_LimitLock != 0 && currentMotionDir2 != 0 && currentMotionDir2 == Axis2_LimitLock;
        const bool hasEscapeMotion = currentMotionDir1 != 0 || currentMotionDir2 != 0;
        const bool isEscaping = hasEscapeMotion && !axis1MovingIntoLimit && !axis2MovingIntoLimit;

        // =========================================================
        // 5. 执行急停
        // =========================================================
        if (!isEscaping) {
            generalError = ERR_LIMIT_SENSE;

            // 物理限位属于硬中断是否需要重新回零统一由
            // stopSlewingAndTracking(SS_LIMIT_PHYSICAL) 判定，避免多处重复修改状态
            stopGuideAxis1(); 
            stopGuideAxis2();
            stopSlewingAndTracking(SS_LIMIT_PHYSICAL);
        }
      } 
    } else {
       // [限位松开]
       if (currentTime - lastLimitTriggerTime > 500) {
           if (guideDirAxis1 == 0 && trackingState != TrackingMoveTo) Axis1_LimitLock=0;
           if (guideDirAxis2 == 0 && trackingState != TrackingMoveTo) Axis2_LimitLock=0;
       }
    }
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

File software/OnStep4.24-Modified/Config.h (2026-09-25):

// ---------------------------------------------------------------------------------------------------------------------------------
// Configuration for OnStep
//测试
/*
 *          For more information on setting OnStep up see http://www.stellarjourney.com/index.php?r=site/equipment_onstep 
 *                      and join the OnStep Groups.io at https://groups.io/g/onstep
 * 
 *           *** Read the compiler warnings and errors, they are there to help guard against invalid configurations ***
*/

// ---------------------------------------------------------------------------------------------------------------------------------
// ADJUST THE FOLLOWING TO CONFIGURE YOUR CONTROLLER FEATURES ----------------------------------------------------------------------
// <-Req'd = always must set, <-Often = usually must set, Option = optional, Adjust = adjust as req'd, Infreq = infrequently changed

// 引脚映射(PINMAP) ------------------------------------------------- see https://onstep.groups.io/g/main/wiki/Configuration-Controller#PINMAP
//   *** See the matching Pins.xxx.h file for your setup (found by looking in src/pinmaps/Models.h) with detailed information ***
//   *** to be sure it matches your wiring.            *** USE AT YOUR OWN RISK ***                                           ***

// 参数名(Parameter Name)              Value   Default  Notes                                                                      Hint
#define PINMAP                    MaxESP3 //    OFF, Choose from: MksGenL2, MiniPCB2, MaxPCB2, MaxESP3, CNC3, STM32Blue,     <-Req'd
                                          //    关闭，从以下选项中选择：MksGenL2、MiniPCB2、MaxPCB2、MaxESP3、CNC3、STM32蓝色，<-需要
                                          //    MaxSTM3, FYSETC_S6_2, etc.  其他主板和更多信息，在Constants.h

// 串口通信通道(SERIAL PORT COMMAND CHANNELS) --------------------------- see https://onstep.groups.io/g/main/wiki/Configuration-Controller#SERIAL
#define SERIAL_A_BAUD_DEFAULT        9600 //   9600, n. Where n=9600,19200,57600,115200 (common baud rates.)                  Infreq
                                          //   9600，n.其中n=9600，19200，57600，115200（常见波特率）
#define SERIAL_B_BAUD_DEFAULT        9600 //   9600, n. See (src/HAL/) for your MCU Serial port # etc.                        Option
                                          //   9600, n. 查看 (src/HAL/) 确认你的MCU串口号等信息
#define SERIAL_B_ESP_FLASHING        OFF  //    OFF, ON Upload ESP8266 WiFi firmware through SERIAL_B with :ESPFLASH# cmd.    Option
                                          //    OFF, ON 通过串口B给ESP8266 WiFi模块刷固件（使用 :ESPFLASH# 命令）
#define SERIAL_C_BAUD_DEFAULT         ON  //    OFF, n, ON for ESP32 Bluetooth.                                               Option
                                          //    OFF, n, 如果是ESP32蓝牙则设为ON
#define SERIAL_C_BLUETOOTH_NAME  "OnStep" // "On..", Bluetooth device name for ESP32.                                         Option
                                          //  ESP32的蓝牙设备名称

// 赤道仪类型(MOUNT TYPE) ----------------------------------------- see https://onstep.groups.io/g/main/wiki/Configuration-Controller#MOUNT_TYPE
#define MOUNT_TYPE                    GEM //    GEM, GEM for German Equatorial, FORK for Equatorial Fork, or ALTAZM          <-Req'd
                                          //    GEM, GEM=德式赤道仪, FORK=叉式赤道仪, ALTAZM=经纬仪
                                          //    Dobsonian etc. mounts. GEM Eq mounts perform meridian flips.
                                          //    Dobsonian (道布森) 等也算经纬仪, 注意：只有 GEM 模式会执行中天翻转

// 用户反馈(USER FEEDBACK) ----------------------------------- see https://onstep.groups.io/g/main/wiki/Configuration-Controller#USER_FEEDBACK
#define LED_STATUS                     ON //     ON, Blinks w/sidereal tracking otherwise steady on indicates activity.       Option
                                          //     ON, 恒星速跟踪时闪烁，常亮表示有其他活动（如GOTO）
#define LED_STATUS2                   OFF //    OFF, ON Blinks 1s interval w/PPS sync, steady for gotos, off if in standby.   Option
                                          //    OFF, ON 收到PPS同步信号闪烁1秒，GOTO时常亮，待机时灭
#define LED_RETICLE                   OFF //    OFF, n. Where n=0..255 (0..100%) activates feature sets default brightness.   Option
                                          //    OFF, n. n=0..255 (0..100%) 开启极轴镜照明功能并设置默认亮度
#define BUZZER                        OFF //    OFF, ON, n. Where n=100..6000 (Hz freq.) for piezo speaker. ON for buzzer.    Option
                                          //    OFF, ON, n. n=100..6000 (Hz频率) 适用于压电喇叭如果是普通有源蜂鸣器填ON
#define BUZZER_STATE_DEFAULT          OFF //    OFF, ON Start with piezo buzzer/speaker enabled.                              Option
                                          //    OFF, ON 启动时默认开启蜂鸣器/喇叭声音
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

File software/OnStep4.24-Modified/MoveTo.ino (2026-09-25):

// -----------------------------------------------------------------------------------
// Functions to move the mount to the a new position

// moves the mount
void moveTo() {
  // HA goes from +90...0..-90
  //                W   .   E
  // meridian flip, first phase.  only happens for GEM mounts
  if ((pierSideControl == PierSideFlipEW1) || (pierSideControl == PierSideFlipWE1)) {

    // save destination
    cli(); 
    origTargetAxis1.fixed = targetAxis1.fixed;
    origTargetAxis2.fixed = targetAxis2.fixed;
 
    timerRateAxis1=siderealRate;
    timerRateAxis2=siderealRate;
    sei();

    // first phase, decide if we should move to 60 deg. HA (4 hours) to get away from the horizon limits or just go straight to the home position
    if (pierSideControl == PierSideFlipWE1) {
      if (homePositionAxis1 == 0.0) setTargetAxis1(0.0,PierSideWest); else {
        if ((currentAlt < 10.0) && (getStartAxis1() > -90.0)) setTargetAxis1(-60.0,PierSideWest); else setTargetAxis1(-homePositionAxis1,PierSideWest);
      }
      setTargetAxis2(homePositionAxis2,PierSideWest);
    } else {
      if (homePositionAxis1 == 0.0) setTargetAxis1(0.0,PierSideEast); else {
        if ((currentAlt < 10.0) && (getStartAxis1() < 90.0)) setTargetAxis1(60.0,PierSideEast); else setTargetAxis1(homePositionAxis1,PierSideEast);
      }
      setTargetAxis2(homePositionAxis2,PierSideEast);
    }

    // first phase, override above for additional waypoints
    if (homePositionAxis2 > 0.0) {
      if (getInstrAxis2() > 90.0-latitude) {
        // if Dec is in the general area of the pole, slew both axis back at once
        if (pierSideControl == PierSideFlipWE1) setTargetAxis1(-homePositionAxis1,PierSideWest); else setTargetAxis1(homePositionAxis1,PierSideEast);
      } else {
        // if we're at a low latitude and in the opposite sky, |HA|=6 is very low on the horizon in this orientation and we need to delay arriving there during a meridian flip
        // in the extreme case, where the user is very near the (Earths!) equator an Horizon limit of -10 or -15 may be necessary for proper operation.
        if (currentAlt < 20.0 && latitudeAbs < 45.0 && getInstrAxis2() < 0.0) {
          if (pierSideControl == PierSideFlipWE1) setTargetAxis1(-45.0,PierSideWest); else setTargetAxis1(45.0,PierSideEast);
        }
      }
    } else {
      if (getInstrAxis2() < -90.0-latitude) {
        // if Dec is in the general area of the pole, slew both axis back at once
        if (pierSideControl == PierSideFlipWE1) setTargetAxis1(-homePositionAxis1,PierSideWest); else setTargetAxis1(homePositionAxis1,PierSideEast);
      } else { 
        // if we're at a low latitude and in the opposite sky, |HA|=6 is very low on the horizon in this orientation and we need to delay arriving there during a meridian flip
        if (currentAlt < 20.0 && latitudeAbs < 45.0 && getInstrAxis2() > 0.0) {
          if (pierSideControl == PierSideFlipWE1) setTargetAxis1(-45.0,PierSideWest); else setTargetAxis1(45.0,PierSideEast);
        }
      }
    }

    pierSideControl++;
    forceRefreshGetEqu();
  }

  long distStartAxis1,distStartAxis2,distDestAxis1,distDestAxis2;

  cli();
  distStartAxis1=labs(posAxis1-startAxis1);  // distance from start Axis1
  distStartAxis2=labs(posAxis2-startAxis2);  // distance from start Axis2
  sei();
  if (distStartAxis1 < 1) distStartAxis1=1;
  if (distStartAxis2 < 1) distStartAxis2=1;

  cli();
  distDestAxis1=labs(posAxis1-(long)targetAxis1.part.m);  // distance from dest Axis1
  distDestAxis2=labs(posAxis2-(long)targetAxis2.part.m);  // distance from dest Axis2
  sei();
  
  // adjust rates near the horizon to help keep from exceeding the minAlt limit
  #if MOUNT_TYPE != ALTAZM
    if (latitudeAbs > 10) {
      long posAxis2=latitudeSign*getInstrAxis2()*axis2Settings.stepsPerMeasure;
      static long lastPosAxis2=0;
      double distDestLimit=currentAlt-(minAlt+10.0); if (distDestLimit < SLEW_ACCELERATION_DIST/8.0) distDestLimit=SLEW_ACCELERATION_DIST/8.0;  
      // if Dec is decreasing slow down the Dec axis, if Dec is increasing slow down the RA axis
      if (posAxis2 < lastPosAxis2) {
        if (distDestLimit*axis2Settings.stepsPerMeasure < distDestAxis2) distDestAxis2=distDestLimit*axis2Settings.stepsPerMeasure;
      } else {
        if (distDestLimit*axis1Settings.stepsPerMeasure < distDestAxis1) distDestAxis1=distDestLimit*axis1Settings.stepsPerMeasure;
      }
      lastPosAxis2=posAxis2;
    }
  #endif

  if (distDestAxis1 < 1) distDestAxis1=1;
  if (distDestAxis2 < 1) distDestAxis2=1;

  // quickly slow the motors and stop in SLEW_RAPID_STOP_DIST
  static double deaccXPerSec=0;
  static double a1r=0;
  static double a2r=0;
  if (abortGoto == 1) {
    // aborts any meridian flip
    if ((pierSideControl == PierSideFlipWE1) || (pierSideControl == PierSideFlipWE2) || (pierSideControl == PierSideFlipWE3)) pierSideControl=PierSideWest;
    if ((pierSideControl == PierSideFlipEW1) || (pierSideControl == PierSideFlipEW2) || (pierSideControl == PierSideFlipEW3)) pierSideControl=PierSideEast;
    if (pauseHome) { waitingHome=false; waitingHomeContinue=false; }

    // stop parking/homing
    if (parkStatus == Parking) {
      lastTrackingState=abortTrackingState;
      parkStatus=NotParked;
      nv.write(EE_parkStatus,parkStatus);
    } else
    if (homeMount) {
      lastTrackingState=abortTrackingState;
      homeMount=false;
    }

    // set rate (in X sidereal) at which we slow down from
    double rateXPerSec = RateToXPerSec/(maxRate/16.0);
    double numSecToStop = (SLEW_RAPID_STOP_DIST/(rateXPerSec/240.0));
    deaccXPerSec = (SLEW_RAPID_STOP_DIST/numSecToStop)*240.0;

    abortGoto++;
  }
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

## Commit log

2026-04-28 update 2024-06-17
    [25-100外壳.SLDASM, RA轴+180度.SLDASM, 纬度座.SLDASM]
2026-05-06 change: update the assembly file for the SW2024 mount
    [纬度座.SLDASM]
2026-05-07 update the pictures of the assembly process
2026-05-07 change the pictures of the assembly process, because I found that the previous ones were not clear enough.
2026-05-07 update the assembly process
2026-05-07 update README.md and Assembly.md
2026-05-13 update hardware assembly documentation with new images and details on the assembly process.
2026-05-13 change:delete, pictures/Assembly process/readme.txt
2026-06-03 upadted: 2024-06-03T12:00:00Z
    [BOM_PCB_2026-03-24.xlsx, BOM_PCB_2026-06-03.xlsx]
2026-06-05 update Assembly.md and add Assembly.EN.md
2026-06-07 update BOM and assembly process pictures
    [180度限位盘.SLDPRT, 25-100外壳.SLDASM, 340度限位盘 - DEC.SLDPRT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]
2026-06-07 UPDATE: Update BOM and assembly process pictures
2026-06-07 udpate Assembly.md
2026-06-07 update BOM and assembly guide
    [MechanicalBOM.xlsx]
2026-06-07 updated Assembly.md with more detailed assembly instructions and additional reference images for the assembly process. The changes include a reorganization of the assembly steps into three distinct p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
2026-06-07 update Assembly.md and Assembly.EN.md
2026-06-07 update hardware assembly instructions for better clarity and accuracy. Adjusted formatting and wording for improved readability.
2026-06-07 fix: Update assembly instructions for better clarity and accuracy
2026-06-07 fix: Update README and Assembly instructions
2026-07-06 update readme to reflect current state of software
2026-07-15 update README.md to reflect the current verification status of the project.
2026-07-15 fix readme images and assembly link
2026-07-15 update pcb
2026-07-15 update README_CN.md, README_EN.md, Assembly_CN.md, Assembly_EN.md, Firmware_Setup_CN.md, Firmware_Setup_EN.md
2026-07-15 change README_CN.md to README.md, change Assembly_CN.md to Assembly.md, change Firmware_Setup_CN.md to Firmware_Setup.md
2026-07-17 fix goto command for equatorial mount
    [Config.h, Home.ino, MoveTo.ino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]
2026-09-25 更新固件修复了可能遇到的bug
2026-09-25 修改注释
